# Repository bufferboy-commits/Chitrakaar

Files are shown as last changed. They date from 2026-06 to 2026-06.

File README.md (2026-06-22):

<div align="center">

# Chitrakaar
**2D CNC Pen Plotter**








</div>

---

## Overview

Chitrakaar is a belt-driven 2D CNC pen plotter that autonomously reproduces digital images on paper. The system extracts edges from an input image, converts them into G-code toolpaths, and executes them via an Arduino-based motion controller driving two stepper motors and a servo-actuated pen lift mechanism.

```
Input Image → MATLAB (G-code) → Python (Serial) → Arduino (Motion) → Paper
```
---

## Hardware

| Component | Specification |
|---|---|
| Microcontroller | Arduino Uno R4 |
| Motor Shield | CNC Shield V3 |
| Stepper Drivers | A4988 × 2 |
| Stepper Motors | NEMA 17 × 2 |
| Servo Motor | Standard PWM servo |
| Linear Motion | 8mm chrome-steel rods + LM8UU bearings |
| Drive Mechanism | Timing belt and pulley |
| Pen Lift | Servo-actuated rack and pinion |
| Power Supply | 12V DC adapter |

> Full bill of materials: [`2d-Printer List of Items.csv`](2d-Printer%20List%20of%20Items.csv)

---

## Mechanical Design

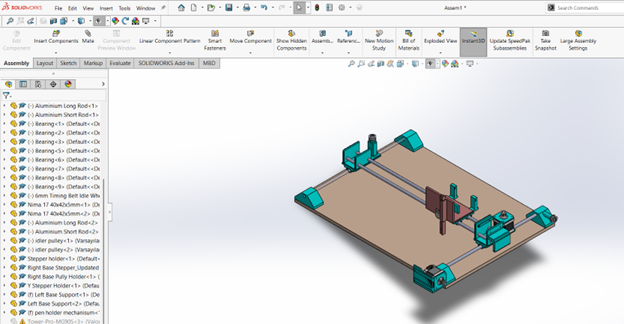
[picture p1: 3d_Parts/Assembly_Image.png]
Assembly


The frame uses chrome-plated carbon-steel smooth rods on a rigid rectangular base. X and Y axes use LM8UU linear bearings riding on 8mm guide rods, driven by NEMA 17 steppers via timing belts. The Z-axis pen lift is achieved through a servo motor coupled to a rack-and-pinion mechanism, converting angular displacement into precise vertical pen motion. The drawing surface remains stationary throughout operation.

> CAD files: [`3d_Parts/`](3d_Parts/)

---

## Electronics

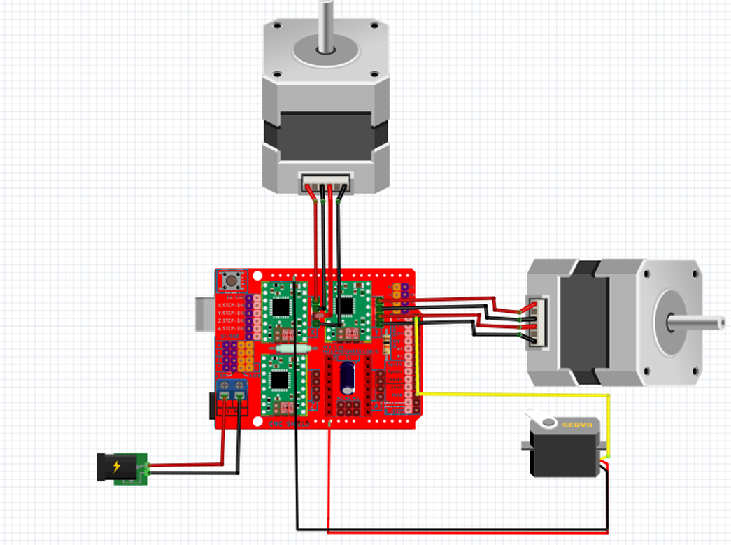
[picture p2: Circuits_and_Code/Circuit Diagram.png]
Circuit Diagram


The CNC Shield V3 mounts directly onto the Arduino Uno R4. A4988 drivers are seated in the X and Y slots. The servo connects to the onboard Pin 11 servo header on the shield.

> Detailed wiring reference: [`Circuits_and_Code/Connections.txt`](Circuits_and_Code/Connections.txt)

---

## Physical Build

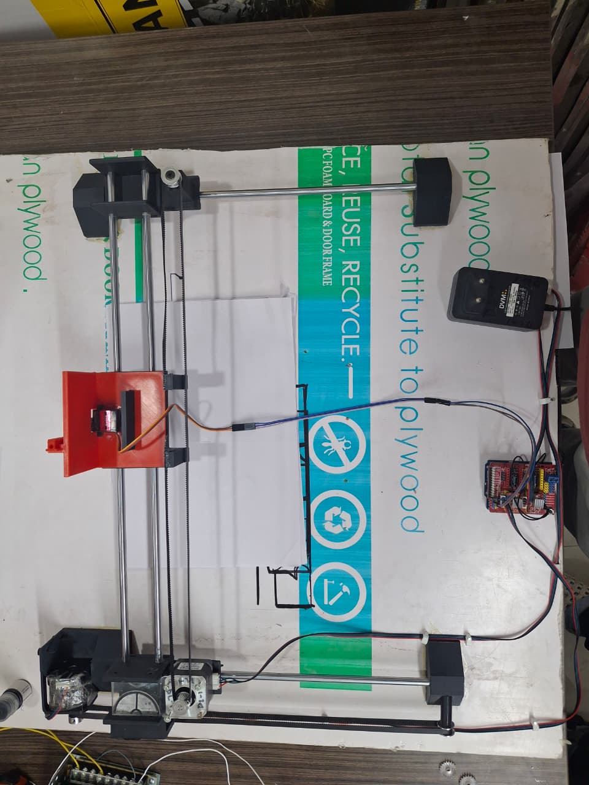
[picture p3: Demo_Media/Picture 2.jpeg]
IRL Model


---

## Software Pipeline

### 1. G-code Generation - MATLAB
**File:** `Image_to_GCode/ImagetoGCodeConverter.m`

Processes an input image into a `.gcode` toolpath file. Performs binary thresholding, manual edge detection, nearest-neighbour path ordering, coordinate scaling, and pen-lift segmentation. Outputs `M3` (pen down) and `M5` (pen up) commands at stroke boundaries.

**Key parameters:**
| Parameter | Effect |
|---|---|
| `step` | Point density - lower value gives smoother output (`1` = maximum quality) |
| `scale` | Physical drawing size |
| `dist` threshold | Pen lift sensitivity - lower value reduces mid-stroke lifts |

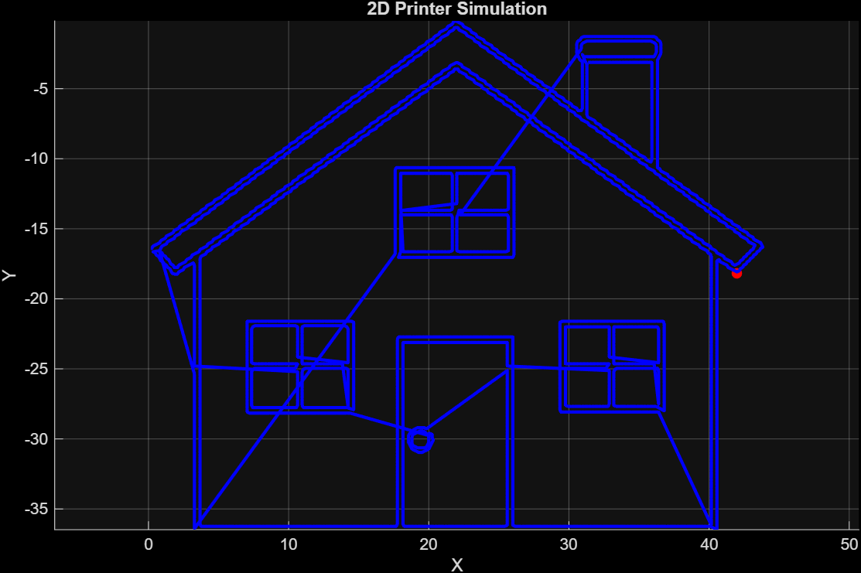
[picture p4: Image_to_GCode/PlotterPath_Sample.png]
Sample Path Plot


### 2. Serial Communication - Python
**File:** `Circuits_and_Code/Plotter_Code.py`

Transmits the generated G-code to the Arduino line by line over USB serial. Update the COM port and filename before running:

```python
ser = serial.Serial('COM3', 115200)   # update port as needed
open("Yourgcodefilepath.gcode", "r")            # update filename to match output
```

### 3. Firmware - Arduino
**File:** `Circuits_and_Code/Stepper_Servo_Controller.cpp`

Custom G-code interpreter running on the Arduino. Parses incoming commands, drives X/Y steppers via the A4988 drivers, and controls the servo for pen actuation. Sends `done` over serial after each command is executed.

**Supported commands:**
| Command | Action |
|---|---|
| `G1 X__ Y__` | Move to coordinate (drawing stroke) |
| `G0 X__ Y__` | Rapid travel (pen lifted) |
| `M3` | Lower pen (servo → 30°) |
| `M5` | Raise pen (servo → 90°) |

---

## Repository Structure

```
CNC-PENPLOTTER/
├── 3d_Parts/                        ← SolidWorks assembly + STL files
├── Circuits_and_Code/               ← Arduino firmware, Python sender, circuit diagram, wiring reference
├── Demo_Media/                      ← Build photos and demo video
├── Image_to_GCode/                  ← MATLAB script, sample input image, sample G-code, simulation output
├── 2d-Printer List of Items.csv     ← Bill of materials
└── README.md
```

---

## How to Run

```
1. Upload  Stepper_Servo_Controller.cpp  to Arduino via Arduino IDE (USB only, no 12V)
2. Run     ImagetoGCodeConverter.m       in MATLAB - update image path and output path
3. Connect hardware - CNC shield on Arduino, steppers to X/Y headers, servo to Pin 11, 12V to shield
4. Run     python Circuits_and_Code/Plotter_Code.py  - update COM port if needed
```

---

## Acknowledgements

Developed as part of **ME-205: Design Lab-I** at the **Indian Institute of Technology Ropar**, under the supervision of **Dr. Satwinder Jit Singh**.

*March 2026 - April 2026*

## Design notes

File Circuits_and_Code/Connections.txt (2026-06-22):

================================================================
CNC 2D PEN PLOTTER - WIRING GUIDE
Arduino Uno R4 + CNC Shield V3 + 2x Stepper + 1x Servo
================================================================
----------------------------------------------------------------
STEPPER DRIVER PLACEMENT
----------------------------------------------------------------
X slot (C1)  --> Insert A4988 driver
Y slot (C2)  --> Insert A4988 driver
Z slot       --> Empty (not used)
A slot       --> Empty (not used)

----------------------------------------------------------------
POWER CONNECTIONS
----------------------------------------------------------------
USB cable         --> Arduino Uno R4 (for code upload and
                      Python serial communication)

12V DC Adapter    --> CNC Shield power terminal
  Positive (+)    --> + on shield (labeled 12-36V)
  Negative (-)    --> - on shield (labeled 12-36V)

----------------------------------------------------------------
SERVO MOTOR --> Servo header on CNC Shield (Pin 11)
----------------------------------------------------------------
Signal wire  (Orange/Yellow) --> Signal pin on shield servo header
VCC wire     (Red)           --> 5V pin on shield servo header
GND wire     (Brown/Black)   --> GND pin on shield servo header

NOTE: This header on the shield corresponds to Arduino Pin 11
which matches SERVO_PIN 11 defined in the Arduino code

----------------------------------------------------------------
IMPORTANT NOTES
----------------------------------------------------------------
1. Check stepper motor datasheet for correct coil pairs
   Wrong pairing = motor vibrates but does not move

2. Set A4988 current limit before first run
   Prevents motors and drivers from overheating

3. Servo gets 5V from Arduino, not from 12V supply

4. Never unplug stepper wires while power is on
   This instantly damages the A4988 driver

5. When uploading code, USB only is fine
   When running the machine, both USB and 12V must be connected

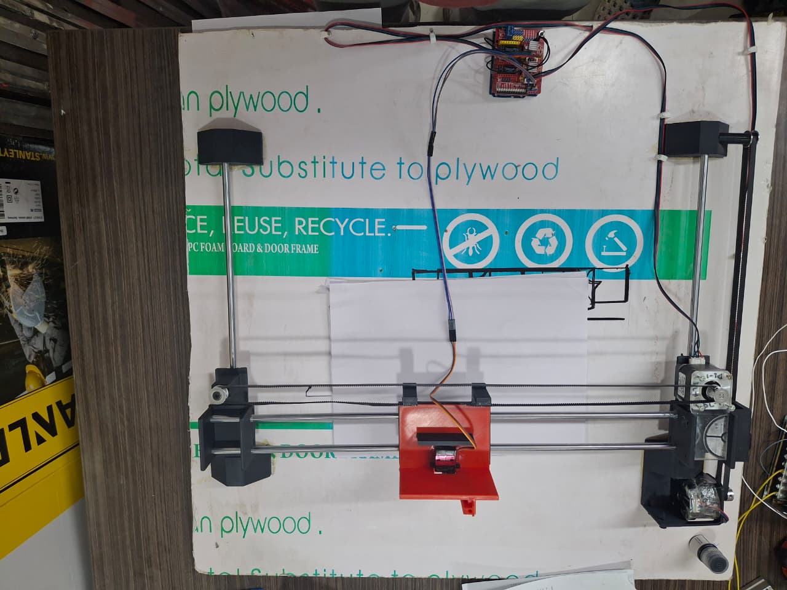
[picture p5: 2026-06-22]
Demo_Media/Picture4.jpeg

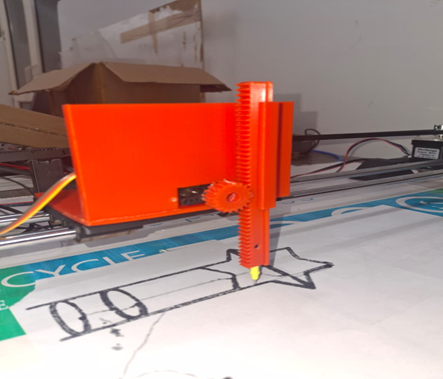
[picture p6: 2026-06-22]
Demo_Media/Picture3.png

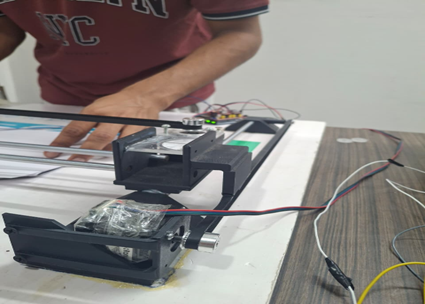
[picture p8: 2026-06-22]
Demo_Media/Picture1.png

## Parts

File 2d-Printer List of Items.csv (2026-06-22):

 | Component | Qty | Link
1 | NEMA 17 Stepper Motor | 2 | https://robu.in/product/nema17-4-2-kgcm-stepper-motor/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
2 | DRV8825 Stepper Driver | 2 | https://robu.in/product/a4988-driver-stepper-motor-driver/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
3 | Arduino Uno | 1 | https://robu.in/product/arduino-uno-r3-ch340g-atmega328p-devlopment-board/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
4 | CNC Shield V3 | 1 | https://robu.in/product/cnc-shield-v3-engraving-machine-3d-printer-a4988-drv8825-driver-expansion-board/
5 | MG90 Servo Motor | 1 | https://robu.in/product/towerpro-mg90s-mini-digital-servo-motor-180-rotation-standard-quality/?gad_source=1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
6 | 12V 2A Adapter | 1 | https://robu.in/product/standard-12v-2a-power-supply-with-5-5mm-dc-plug-3-pin-input-plug/?gad_source=1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
7 | Chrome Plated Smooth Rod Diameter 8 MM | 4 | https://robu.in/product/380-mm-long-chrome-plated-smooth-rod-diameter-8-mm/
8 | LM8MU Linear Bearings | 4 | https://robu.in/product/lm8uu-8-mm-linear-bearings-linear-motion-bearing/
9 | M3 Screws | 20
10 | M3-Nut Bolt | 8
11 | GT2 Belt & Pulley Set | 2 sets | https://robu.in/product/1m-gt2-width-6mm-black-open-timing-belt-for-3d-printer/?gad_source=1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
12 | Idler Pulley | 2 | https://robu.in/product/aluminum-gt2-timing-idler-pulley-6mm-belt-20-tooth-5mm-bore-2pcs/?gad_source=1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

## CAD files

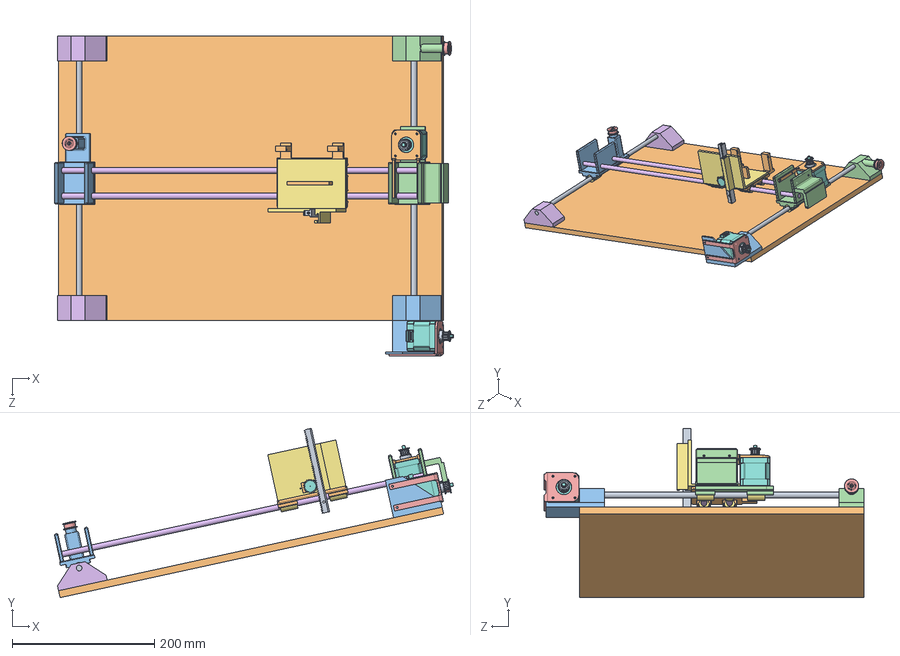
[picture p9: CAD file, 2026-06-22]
3d_Parts/Assem1.SLDASM
561.0 x 238.1 x 450.0 mm
Central Clamp
Left Slider Clamp_Updated
Right Slider Clamp
6mm Timing Belt Idle Wheel x 2
Aluminium Long Rod x 2
Aluminium Short Rod x 2
Bearing x 8
Nima 17 40x42x5mm x 2
idler pulley x 2
Stepper holder
Right Base Stepper_Updated
Right Base Pully Holder
Y Stepper Holder
Left Base Support x 2
pen holder mechanisum
spur gear_am
Rack
Part2^Assem1

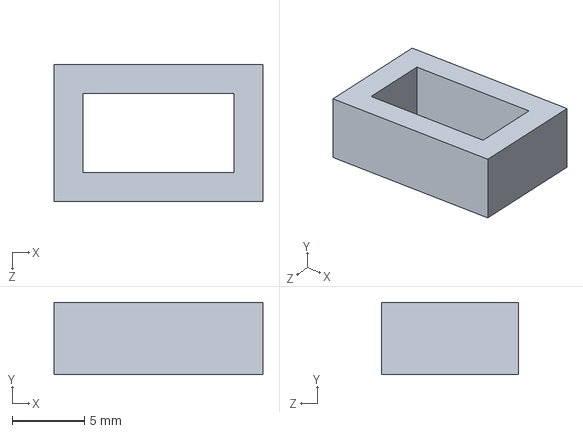
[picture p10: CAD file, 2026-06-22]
3d_Parts/Parts to 3DPrint/Cap_TwoHoled Holder.SLDPRT
14.5 x 5.00 x 9.50 mm

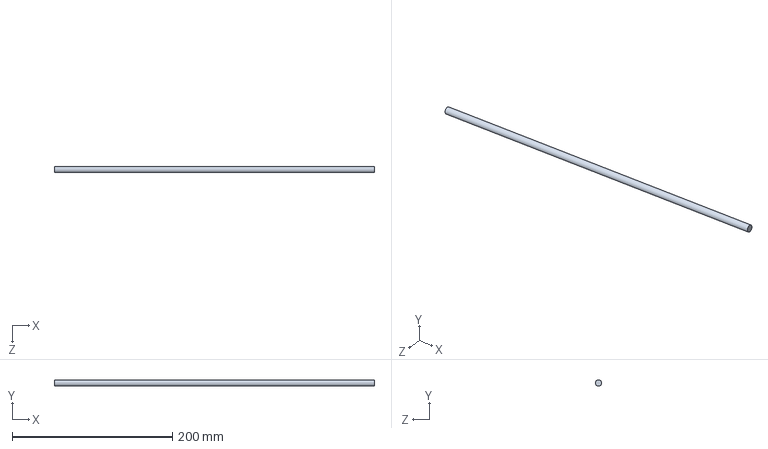
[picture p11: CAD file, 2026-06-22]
3d_Parts/Readymade/Aluminium Long Rod.SLDPRT
400.0 x 8.00 x 8.00 mm

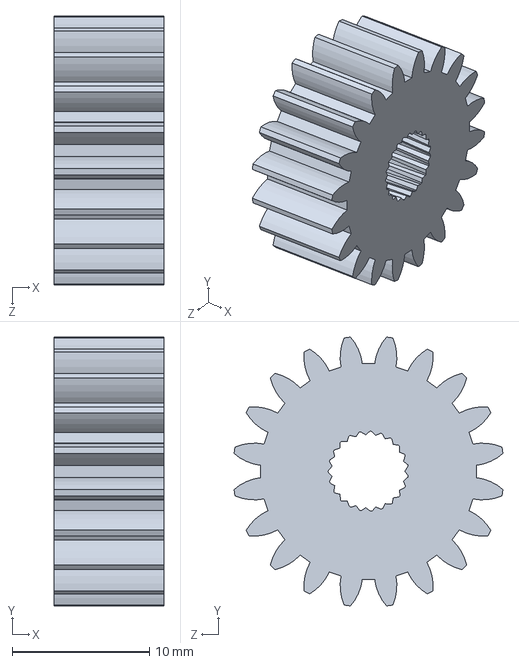
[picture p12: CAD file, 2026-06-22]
3d_Parts/Parts to 3DPrint/Gear.SLDPRT
8.00 x 19.6 x 19.6 mm

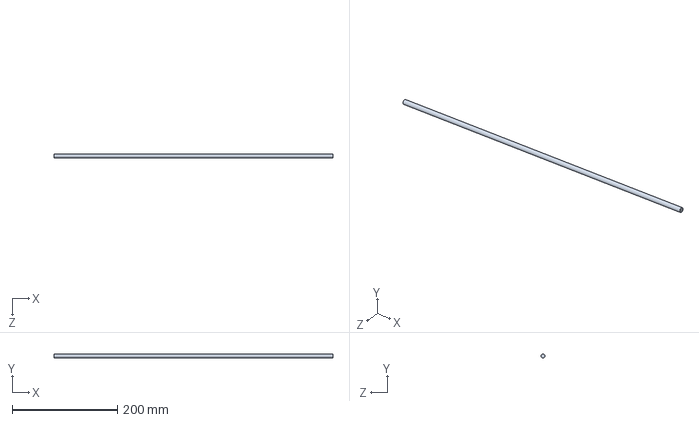
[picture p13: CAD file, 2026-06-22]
3d_Parts/Readymade/Aluminium Short Rod.SLDPRT
530.0 x 8.00 x 8.00 mm

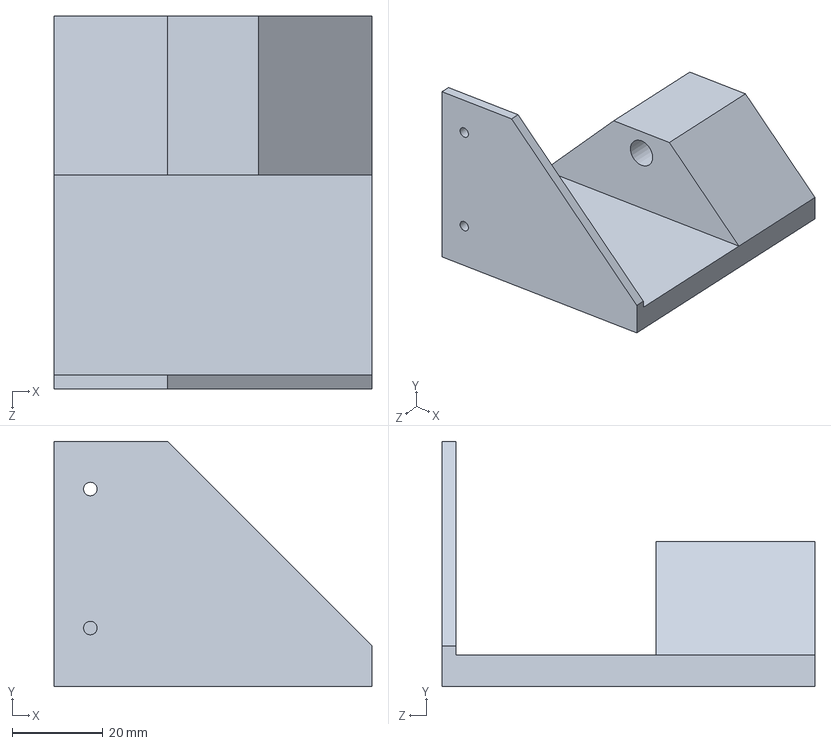
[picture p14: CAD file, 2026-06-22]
3d_Parts/Parts to 3DPrint/Right Base Stepper_Updated.SLDPRT
70.0 x 54.0 x 82.0 mm

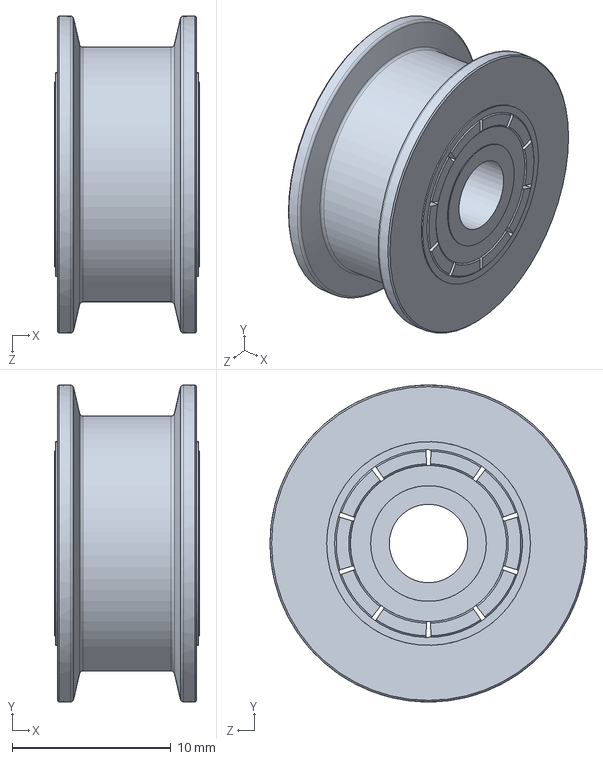
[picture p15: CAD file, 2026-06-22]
3d_Parts/Readymade/6mm Timing Belt Idle Wheel.SLDPRT
9.15 x 20.0 x 20.0 mm

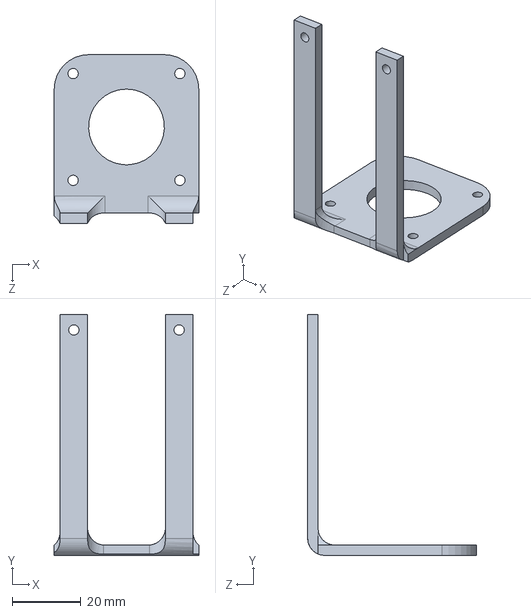
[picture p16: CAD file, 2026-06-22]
3d_Parts/Parts to 3DPrint/Y Stepper Holder.SLDPRT
42.0 x 70.0 x 49.0 mm

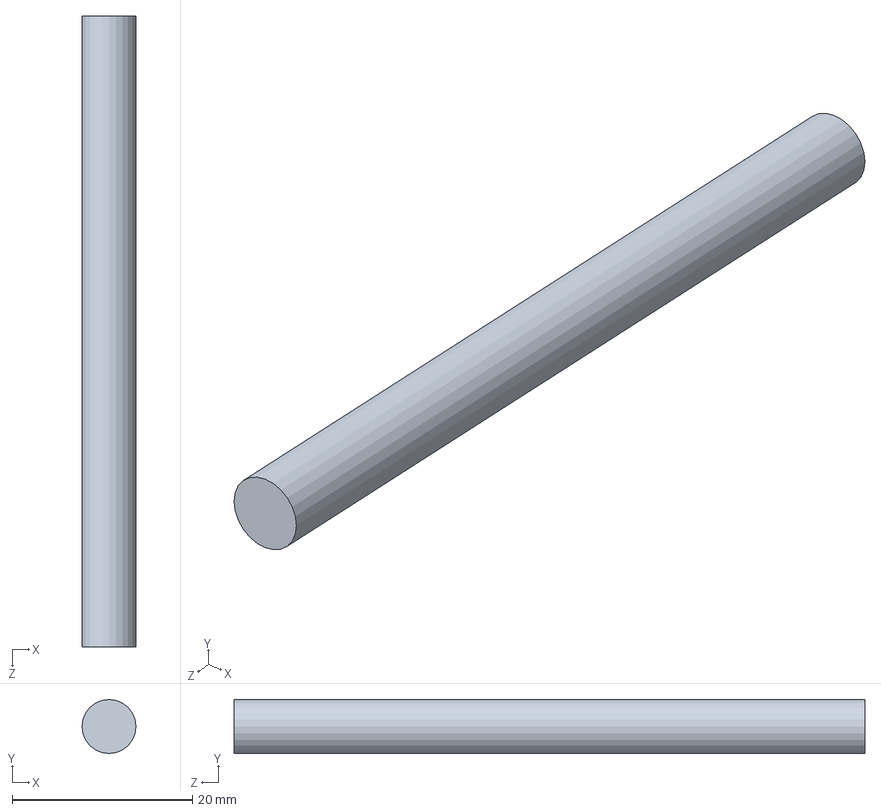
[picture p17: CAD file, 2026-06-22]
3d_Parts/Readymade/CF_Rod.SLDPRT
6.00 x 6.00 x 70.0 mm

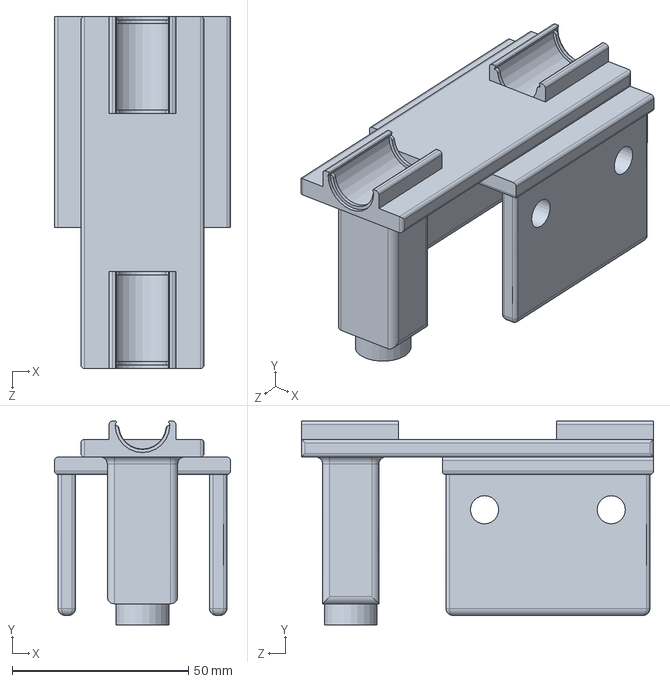
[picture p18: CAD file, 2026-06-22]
3d_Parts/Parts to 3DPrint/Left Slider Clamp_Updated.SLDPRT
50.0 x 57.9 x 100.0 mm

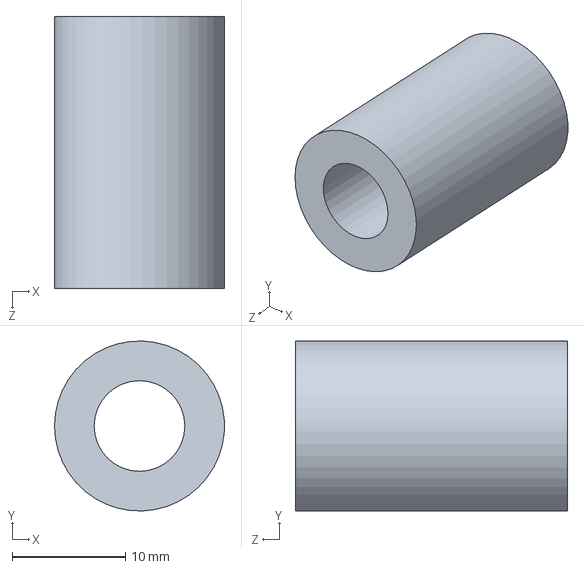
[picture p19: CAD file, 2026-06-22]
3d_Parts/Readymade/Bearing.SLDPRT
15.0 x 15.0 x 24.0 mm

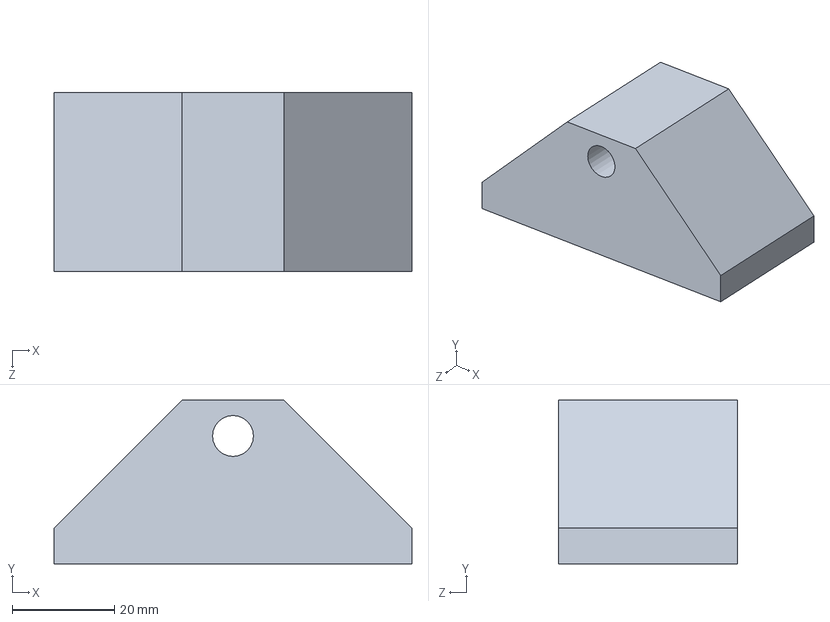
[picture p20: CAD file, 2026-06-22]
3d_Parts/Parts to 3DPrint/Right Base Stepper Support.SLDPRT
70.0 x 32.0 x 35.0 mm

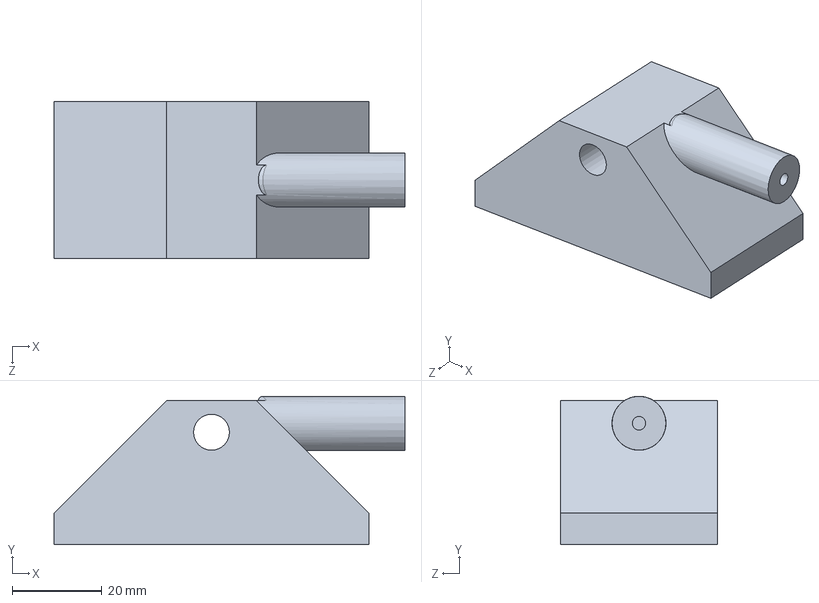
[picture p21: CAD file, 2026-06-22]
3d_Parts/Parts to 3DPrint/Right Base Pully Holder.SLDPRT
78.0 x 33.0 x 35.0 mm

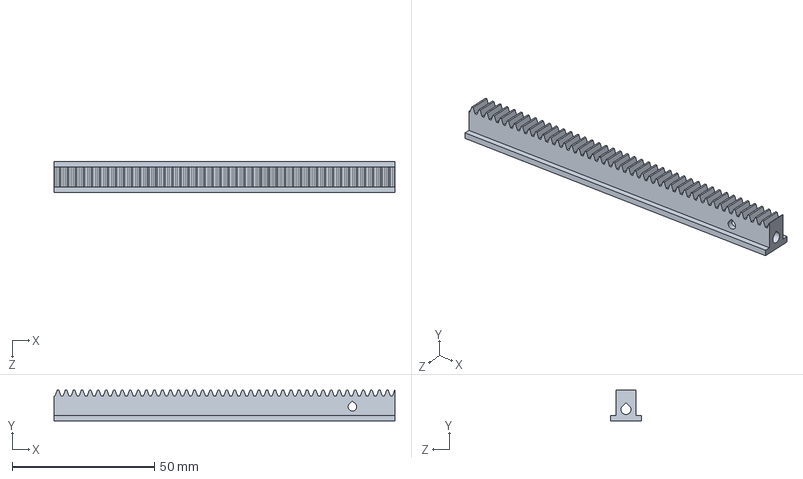
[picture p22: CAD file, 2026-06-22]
3d_Parts/Parts to 3DPrint/Rack.SLDPRT
120.0 x 10.9 x 11.0 mm

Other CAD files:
3d_Parts/Parts to 3DPrint/pen holder mechanisum.SLDPRT
3d_Parts/Parts to 3DPrint/Left Base Support.SLDPRT
3d_Parts/Parts to 3DPrint/Right Slider Clamp.SLDPRT
3d_Parts/Parts to 3DPrint/Central Clamp.SLDPRT

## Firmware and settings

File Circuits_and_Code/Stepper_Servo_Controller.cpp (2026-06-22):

#include <Servo.h>

// X Axis
#define X_STEP 2
#define X_DIR 5

// Y Axis
#define Y_STEP 3
#define Y_DIR 6

// Enable pin
#define ENABLE 8

// Servo
#define SERVO_PIN 11

Servo penServo;

// Position tracking
int currentX = 0;
int currentY = 0;

// Pen positions
int penUp = 90;
int penDown = 30;

void setup() {

  Serial.begin(115200);

  pinMode(X_STEP, OUTPUT);
  pinMode(X_DIR, OUTPUT);

  pinMode(Y_STEP, OUTPUT);
  pinMode(Y_DIR, OUTPUT);

  pinMode(ENABLE, OUTPUT);

  digitalWrite(ENABLE, LOW);

  penServo.attach(SERVO_PIN);

  penServo.write(penUp);
}

void loop() {

  if (Serial.available()) {

    String cmd = Serial.readStringUntil('\n');
    cmd.trim();

    if (cmd.startsWith("G1")) {

      int xIndex = cmd.indexOf('X');
      int yIndex = cmd.indexOf('Y');

      int targetX = currentX;
      int targetY = currentY;

      if (xIndex != -1) {
        targetX = cmd.substring(xIndex + 1).toInt();
      }

      if (yIndex != -1) {
        targetY = cmd.substring(yIndex + 1).toInt();
      }

      moveTo(targetX, targetY);
    }

    // Pen down
    if (cmd.startsWith("M3")) {
      penServo.write(penDown);
      delay(500);
    }

    // Pen up
    if (cmd.startsWith("M5")) {
      penServo.write(penUp);
      delay(500);
    }

    Serial.println("done");
  }
}

void moveTo(int targetX, int targetY) {

  int dx = targetX - currentX;
  int dy = targetY - currentY;

  digitalWrite(X_DIR, dx > 0 ? HIGH : LOW);
  digitalWrite(Y_DIR, dy > 0 ? HIGH : LOW);

  dx = abs(dx);
  dy = abs(dy);

  int steps = max(dx, dy);

  for (int i = 0; i < steps; i++) {

    if (i < dx) {
      digitalWrite(X_STEP, HIGH);
    }

    if (i < dy) {
      digitalWrite(Y_STEP, HIGH);
    }

    delayMicroseconds(800);

    digitalWrite(X_STEP, LOW);
    digitalWrite(Y_STEP, LOW);

    delayMicroseconds(800);
  }

  currentX = targetX;
  currentY = targetY;
}

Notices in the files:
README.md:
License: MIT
